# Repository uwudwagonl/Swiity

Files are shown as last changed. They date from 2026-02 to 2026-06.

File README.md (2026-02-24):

# Swiity – Vending Machine Project

**HTLVB 4AHWII Gruppe C**

A fully integrated vending machine project combining:

- **PLC / SPS control** – written in Structured Text (ST) with Automation Studio (B&R)
- **Arduino sensing** – sensor and actuator control via Arduino microcontrollers
- **Mechanical design** – CAD models, STL files, and 3D-printed parts
- **Electrical design** – wiring diagrams and schematics

---

## Repository Structure

```
Swiity/
├── AutomationStudio/          # PLC program (Structured Text, B&R Automation Studio)
│   └── VendingMachine/
│       ├── Main.st            # Main cyclic task
│       ├── StateMachine.st    # Vending state-machine logic
│       ├── Types.typ          # User-defined data types (UDTs)
│       └── Variables.var      # Global variable declarations
│
├── Arduino/                   # Arduino firmware for sensors & actuators
│   └── VendingMachine/
│       ├── VendingMachine.ino # Main Arduino sketch
│       ├── Sensors.h          # Sensor pin definitions and helper functions
│       └── Actuators.h        # Actuator pin definitions and helper functions
│
├── CAD/                       # Computer-aided design files
│   ├── Models/                # Native CAD source files (.step, .f3d, .sldprt, …)
│   └── Images/                # Rendered views and screenshots
│
├── 3DPrinting/                # 3D printing assets
│   ├── STL/                   # STL meshes ready for slicing
│   ├── GCode/                 # Sliced G-code files
│   └── PrintSettings/         # Slicer profiles / settings exports
│
├── Documentation/             # Project documentation
│   ├── Wiring/                # Wiring diagrams (PDF, PNG, Fritzing …)
│   ├── Schematics/            # Electrical schematics
│   └── BOM/                   # Bill of materials (BOM) spreadsheets
│
└── Images/                    # Project photos and renders
```

---

## Getting Started

### Automation Studio (PLC / SPS)

1. Open **B&R Automation Studio**.
2. Select *File → Open Project* and navigate to `AutomationStudio/VendingMachine/`.
3. Build the project (*Build → Build Solution*).
4. Transfer to the target controller via *Online → Transfer*.

### Arduino

1. Open `Arduino/VendingMachine/VendingMachine.ino` in the **Arduino IDE** (≥ 2.x).
2. Select the correct board and COM port.
3. Click *Upload*.

### 3D Printing

1. Find the desired part in `3DPrinting/STL/`.
2. Import the STL into your slicer (PrusaSlicer, Cura, …).
3. Load the matching profile from `3DPrinting/PrintSettings/` if available.
4. Slice, export G-code to `3DPrinting/GCode/`, and print.

---

## Requirements

| Component | Tool / Version |
|---|---|
| PLC code  | B&R Automation Studio 4.x, Structured Text (IEC 61131-3) |
| Arduino | Arduino IDE 2.x, Arduino Uno / Mega (or compatible) |
| CAD | Autodesk Fusion 360 / FreeCAD / SolidWorks |
| Slicing | PrusaSlicer / Cura |

---

## Contributing

1. Create a feature branch: `git checkout -b feature/<your-feature>`
2. Commit your changes with descriptive messages.
3. Open a Pull Request against `main`.

---

## License

See [LICENSE](LICENSE) for details.

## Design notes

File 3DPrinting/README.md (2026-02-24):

# 3DPrinting

3D printing assets for vending machine parts.

## Sub-folders

| Folder | Contents |
|---|---|
| `STL/` | Mesh files ready for slicing (exported from `CAD/Models/`) |
| `GCode/` | Sliced G-code ready to send to the printer |
| `PrintSettings/` | Slicer profiles / settings exports |

## Recommended Print Settings (starting point)

| Parameter | Value |
|---|---|
| Layer height | 0.2 mm |
| Infill | 20 % (structural parts: 40 %) |
| Perimeters | 3 |
| Supports | As needed |
| Material | PLA (enclosure) / PETG (load-bearing parts) |

## Naming Convention

STL files should mirror the CAD part number:

```
<PartNumber>_<Description>.stl
```

Example: `002_ProductSlotTray.stl`

## Workflow

1. Export `.stl` from the CAD model at the correct scale (mm, not inches).
2. Open in your slicer (PrusaSlicer / Cura).
3. Load the matching settings profile from `PrintSettings/`.
4. Slice and save the G-code to `GCode/` with the same part number prefix.
5. Transfer G-code to the printer (SD card / USB / OctoPrint).

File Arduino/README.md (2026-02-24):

# Arduino

Arduino firmware that handles **physical sensor reading** and **actuator driving**
for the vending machine, acting as the I/O front-end to the PLC.

## Files

| File | Purpose |
|---|---|
| `VendingMachine/VendingMachine.ino` | Main sketch – setup, loop, serial protocol |
| `VendingMachine/Sensors.h` | Sensor pin assignments and read helpers |
| `VendingMachine/Actuators.h` | Actuator pin assignments and control helpers |

## Wiring Summary

| Function | Arduino Pin | Notes |
|---|---|---|
| Coin sensor | D2 | Interrupt-capable |
| Product sensor | D3 | Interrupt-capable |
| Door sensor | D4 | Reed switch, INPUT_PULLUP |
| Temperature | A0 | NTC / DS18B20 |
| Stock sensors 0–7 | D5–D12 | IR reflection sensors |
| Motor enable | A1 | PWM output |
| Slot select bit 0 | A2 | 3-bit address LSB |
| Slot select bit 1 | A3 | 3-bit address |
| Slot select bit 2 | A4 | 3-bit address MSB |
| Change solenoid | A5 | Coin-return solenoid |
| Status LED | D13 | Built-in LED |
| Cooling fan | A6 | Relay output |

## Serial Protocol

Baud rate: **115 200**

### Arduino → PLC  (sensor report, sent every 100 ms)

```
S,<coin>,<product>,<door>,<temp>,<s0>,<s1>,<s2>,<s3>,<s4>,<s5>,<s6>,<s7>
```

- `coin`, `product`, `door`, `sN` – `0` or `1`
- `temp` – float (°C), one decimal place

Example: `S,0,0,0,6.4,1,1,1,0,1,1,1,1`

### PLC → Arduino  (actuator command)

```
A,<motorEn>,<slot>,<change>,<statusLED>,<fan>
```

- All fields – `0` or `1` (or slot index 0–7)

Example: `A,1,3,0,1,0`  → motor on, slot 3, change off, LED on, fan off

## How to Flash

1. Open `VendingMachine/VendingMachine.ino` in **Arduino IDE 2.x**.
2. Select the correct board (*Tools → Board*) and port (*Tools → Port*).
3. Click **Upload** (Ctrl + U).

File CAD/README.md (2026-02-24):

# CAD

Computer-Aided Design files for the vending machine enclosure and mechanical parts.

## Sub-folders

| Folder | Contents |
|---|---|
| `Models/` | Native CAD source files (`.f3d`, `.step`, `.iges`, `.sldprt`, …) |
| `Images/` | Rendered views, screenshots, and exploded diagrams |

## Recommended Naming Convention

```
<PartNumber>_<Description>_v<Version>.<ext>
```

Examples:
- `001_OuterEnclosure_v1.step`
- `002_ProductSlotTray_v2.f3d`
- `003_CoinChute_v1.step`

## Software

- **Autodesk Fusion 360** (`.f3d`) – preferred for collaborative editing
- **FreeCAD** (`.FCStd`) – open-source alternative
- **SolidWorks** (`.sldprt` / `.sldasm`) – if available at school

Always export a neutral `.step` file alongside the native format so any team
member can open the geometry regardless of which CAD tool they use.

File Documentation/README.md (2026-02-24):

# Documentation

Project documentation for the vending machine.

## Sub-folders

| Folder | Contents |
|---|---|
| `Wiring/` | Wiring diagrams (Fritzing `.fzz`, PDF exports, PNG images) |
| `Schematics/` | Electrical schematics (KiCad, Eagle, or PDF) |
| `BOM/` | Bill of Materials spreadsheets (`.csv` / `.xlsx`) |

## Document Naming Convention

```
<DocType>_<Description>_v<Version>.<ext>
```

Examples:
- `Wiring_ArduinoToSensors_v1.pdf`
- `Schematic_PowerSupply_v2.pdf`
- `BOM_ElectricalComponents_v1.csv`

## BOM Template

A BOM CSV should contain at minimum:

| Column | Description |
|---|---|
| `ItemNo` | Sequential item number |
| `Quantity` | Number of units required |
| `Description` | Human-readable description |
| `Manufacturer` | Manufacturer name |
| `PartNumber` | Manufacturer part number |
| `Supplier` | Where to order (e.g., DigiKey, Mouser, Conrad) |
| `SupplierPN` | Supplier part number |
| `UnitPrice` | Price per unit (€) |
| `Notes` | Any additional notes |

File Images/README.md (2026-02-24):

# Images

Project photos, renders, and progress pictures.

## What to add here

- Photos of the physical build at each stage
- Renders exported from `CAD/Images/`
- Screenshots of the Automation Studio HMI
- Any promotional or presentation images

## Naming Convention

```
<YYYY-MM-DD>_<Description>.<ext>
```

Examples:
- `2024-03-15_AssemblyFront.jpg`
- `2024-04-02_WiringComplete.jpg`
- `2024-05-10_FinalRender.png`

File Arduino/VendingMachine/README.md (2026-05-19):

# Snackomat ESP32-Firmware

Firmware für den Snackautomaten von Gruppe C (Swiity, Berufsschule).

## Hardware
- ESP32 DevKit (beliebige Variante mit ≥ 30 Pins)
- 4 × HC-SR04 Ultraschall-Sensor
- 4-Kanal Relais-Modul (active HIGH)
- 4 × DC-Getriebemotor 12 V
- PN532 NFC-Leser (I2C-Modus)
- 5 V Netzteil für ESP32, 12 V Netzteil für Motoren (getrennt!)

## Software-Setup

### 1. Arduino IDE konfigurieren
- Arduino IDE ≥ 2.0
- Board-Manager-URL ergänzen:
  `https://raw.githubusercontent.com/espressif/arduino-esp32/gh-pages/package_esp32_index.json`
- Board installieren: **esp32** von Espressif
- Board auswählen: *ESP32 Dev Module*

### 2. Libraries installieren (Library Manager)
- **Adafruit PN532** (aktuellste Version)
- **Adafruit BusIO** (wird automatisch mitgezogen)

`WiFi`, `Preferences`, `Wire` und `esp_task_wdt` sind im ESP32-Core enthalten.

### 3. Konfiguration anpassen
Öffne [config.h](snackomat/config.h) und passe an:
```cpp
#define WIFI_SSID      "Snackomat_WLAN"
#define WIFI_PASSWORD  "bitte-aendern"
#define PLC_IP         "192.168.2.20"      // Deine X20CP1382 IP
#define PLC_TCP_PORT   8000
```

NFC-Whitelist (Karten-UIDs) ebenfalls dort pflegen:
```cpp
static const char* NFC_WHITELIST[NFC_WHITELIST_MAX] = {
    "04A1B2C3D4",   // Schuelerkarte 1
    ...
};
```

### 4. Sketch öffnen und flashen
Öffne `snackomat/snackomat.ino` in der Arduino IDE. Klick auf **Upload**.

### 5. Serial-Monitor
Baudrate `115200`. Erwartete Ausgabe nach Boot:
```
================================================
  Snackomat ESP32-Firmware (Swiity Gruppe C)
================================================
[120ms] NVS geoeffnet (Namespace: snackomat)
[135ms] Sensor Fach 1 initialisiert (TRIG=26, ECHO=27)
...
[450ms] WLAN starte zu SSID 'Snackomat_WLAN' (non-blocking)
[5200ms] WLAN verbunden. IP: 192.168.2.99, RSSI: -63 dBm
[5400ms] TCP verbinde zu 192.168.2.20:8000 ...
[5500ms] TCP-Verbindung zur PLC steht
[5500ms] -> PLC: READY
```

## Dateiübersicht

| Datei | Zweck |
|---|---|
| [snackomat.ino](snackomat/snackomat.ino) | Hauptdatei, setup() + loop() |
| [config.h](snackomat/config.h) | Pins, Konstanten, WLAN, NFC-Whitelist |
| [hcsr04_sensor.h/.cpp](snackomat/hcsr04_sensor.cpp) | Ultraschall, Median aus 3 Messungen |
| [motor_control.h/.cpp](snackomat/motor_control.cpp) | DC-Motor via Relais, nicht-blockierend |
| [sps_communication.h/.cpp](snackomat/sps_communication.cpp) | TCP-Client zur PLC, Protokoll-Parser |
| [fach_manager.h/.cpp](snackomat/fach_manager.cpp) | Orchestriert Sensoren + Motoren (Round-Robin) |
| [preferences_manager.h/.cpp](snackomat/preferences_manager.cpp) | NVS: Kalibrierung, LEER/VOLL, Laufzeit |
| [nfc_reader.h/.cpp](snackomat/nfc_reader.cpp) | PN532 I2C, Whitelist-Prüfung |

## Protokoll (TCP/IP, ASCII, `\n`-getrennt)

### PLC → ESP32
| Befehl | Bedeutung |
|---|---|
| `M:1`  | Motor Fach 1 starten |
| `C:1`  | Fach 1 kalibrieren (Referenzwert speichern) |
| `S:1`  | Status Fach 1 anfordern |
| `A` | Status aller Fächer anfordern |
| `P:1,1.50` | Simulierte Zahlung 1,50 € Fach 1 → Motor starten |
| `PING` | Antwort: `PONG` |

### ESP32 → PLC
| Nachricht | Bedeutung |
|---|---|
| `READY` | System gebootet/verbunden |
| `OK:1` | Motor 1 gestartet |
| `DONE:1` | Motor 1 fertig (nach Laufzeit) |
| `LEER:1` / `VOLL:1` | Bestandsänderung Fach 1 |
| `DIST:1,23`  | Aktueller Abstand Fach 1 in cm |
| `STATUS:1,VOLL` | Antwort auf `S:1` |
| `NFC:04A1B2C3D4,OK` | Karte gescannt, in Whitelist |
| `NFC:04A1B2C3D4,UNBEKANNT` | Karte nicht in Whitelist |
| `PING` | Heartbeat alle 2 s |
| `ERR:WLAN,reconnect` | Fehlermeldung mit Quelle + Detail |

## Pin-Belegung (siehe auch Verkabelung.pdf)

| Komponente | ESP32 Pin |
|---|---|
| HC-SR04 Fach 1 | TRIG=26, ECHO=27 |
| HC-SR04 Fach 2 | TRIG=14, ECHO=12 |
| HC-SR04 Fach 3 | TRIG=33, ECHO=32 |
| HC-SR04 Fach 4 | TRIG=25, ECHO=35 |
| Relais Motor 1 | IN1=16 |
| Relais Motor 2 | IN2=17 |
| Relais Motor 3 | IN3=18 |
| Relais Motor 4 | IN4=19 |
| PN532 SDA | 21 |
| PN532 SCL | 22 |
| PN532 IRQ | 13 |
| PN532 RST | 15 |

## Troubleshooting

### ESP32 bootet in Endlosschleife
- Watchdog schlägt zu. Prüfe Serial-Output, Zeile vor Reset zeigt wo.
- Meist: fehlende Library oder falsche Pin-Nummer.

### Kein WLAN
- SSID/Passwort in config.h korrekt?
- X20CP1382 und ESP32 im gleichen Subnetz (Router-Subnet wie 192.168.2.x)?

### Keine TCP-Verbindung
- PLC-IP in config.h = tatsächliche IP der X20CP1382?
- PLC-Projekt auf X20CP1382 übertragen und läuft?
- Windows-Firewall blockiert Port 8000?

### HC-SR04 liest immer -1
- 5 V Versorgung am Sensor (nicht 3,3 V — HC-SR04 braucht 5 V)?
- TRIG/ECHO nicht verwechselt?

### PN532 nicht gefunden
- Modul im I2C-Modus konfiguriert (DIP-Schalter am Modul!)?
- SDA/SCL nicht verwechselt?
- 3,3 V an VCC (nicht 5 V)?

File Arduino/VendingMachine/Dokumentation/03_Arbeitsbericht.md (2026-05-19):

# Arbeitsbericht: HTLVB_Sweety_Basic → HTLVB_Sweety_new

Projekt Swiity Gruppe C (Berufsschule)
Erweiterung der Schul-Vorlage zum voll funktionsfähigen Snackautomaten
mit ESP32, NFC und TCP/IP-Kommunikation.

---

## 1. Gesamtziel

Die Basis-Vorlage `HTLVB_Sweety_Basic` bietet Grundgerüst für einen
Snackautomaten, steuert aber nur lokal über X20-I/O. Das neue Projekt
`HTLVB_Sweety_new` baut dieses Fundament um zu einem verteilten System
ESP32 ↔ PLC mit Karten-Zahlung und getrennter Hardware für die
Fach-Überwachung.

---

## 2. Hardware-Konfiguration (UNVERÄNDERT übernommen)

Nichts geändert:
- **CPU**: X20CP1382 (IP 192.168.2.20)
- **Panel**: 6PPT50.0502-10A
- **Digital-Input X1**: Münzeinwurf-Lichtschranke (DI01)
- **Digital-Output X3**: 4× Motor (DO01–DO04) + LED (DO05)
- **Analog-Output X20AO2622**: Motor-Geschwindigkeit
- **Automation Runtime**: G4.83

---

## 3. Task-Struktur: ST → ANSI C++ ersetzt

### Entfernt
| Task (Vorlage) | Sprache | Zweck | Ersetzt durch |
|---|---|---|---|
| `visumanager` | Structured Text | Seiten-Navigation, Sprachumschaltung | Program (ANSI C++) |
| `produktausgabe` | Structured Text | Zahlungs-Statemachine, Motorausgabe | Program (ANSI C++) |
| `motorman` | Structured Text | Motor-Tippbetrieb, Settings | Program (ANSI C++) |

### Neu
| Task | Sprache | Zweck |
|---|---|---|
| `Program` | ANSI C++ | Gesamte Geschäftslogik + TCP-Server |
| `Program1` | ANSI C++ | Münz-Zählung mit Entprellung |

**Warum**: Vorgabe des Users — komplette Umstellung auf C++.

---

## 4. Globale Typen (Global.typ) — ERWEITERT

Aus Vorlage beibehalten:
- `eVisuPages` (Seiten-Enum)
- `tVisu_page`, `tVisu_buttons`, `tVisu_settings`, `tVisu`

Neu hinzugefügt (für Snackomat):
- `tFach` – Fach-Info (Abstand, istLeer, Referenz, Preis, Name)
- `tAuswahl` – aktuelle Kundenauswahl
- `tZahlung` – Zahlungsmodus (0=idle, 1=Bar, 2=Karte), Status, Startzeit
- `tNfcInfo` – UID, Whitelist-Status, Zeitstempel
- `tMuenze` – Impulse, Summe, Wert pro Impuls
- `tEspStatus` – ESP32-Verbindung, letzter Ping, Fehlerzähler

Seiten-Enum erweitert:
- Neu: `_20_BarBezahlen`, `_30_KarteBezahlen`, `_40_Ausgabe`, `_50_Danke`, `_90_Fehler`

Button-Struct erweitert:
- Neu: `P10_WaehleBar`, `P10_WaehleKarte`
- Neu: `P20_BestaetigeBar`, `P30_BestaetigeKarte`
- Neu: `PXX_Abbrechen`
- Neu: `P910_Kalibriere1..4`

Settings-Struct erweitert:
- Neu: `muenzwertCent`, `preisCent[0..3]`

---

## 5. Globale Variablen (Global.var) — ERWEITERT

Aus Vorlage beibehalten:
- `Visu`, `aoMotorspeed`, `psMotorspeed`, `diMuenzeinwurf`
- `doMotor[0..3]`, `doLedEin`
- `Perm_ptMotorX[0..3]` (RETAIN)

Neu hinzugefügt:
- `gFach[0..3]` – Fach-Bestandsdaten
- `gSel` – aktuelle Auswahl
- `gPay` – Zahlungsvorgang
- `gNfc` – NFC-Info (kommt vom ESP32)
- `gCoin` – Münzzähler
- `gEsp` – ESP32-Verbindungsstatus
- `do_Relais` – zusätzliches Freigaberelais
- `Perm_preisCent[0..3]`, `Perm_motorLaufzeit[0..3]`, `Perm_muenzwert` (RETAIN)

---

## 6. Visualisierung (Logical/Visu)

### Aus Vorlage beibehalten
- Layout-Basis 800×480 WVGA
- Seiten `_00_Init`, `_10_Main`, `_900_Settings`, `_910_Settings1`
- VCShared, Fonts, Bitmaps, Layers, Styles komplett unverändert
- HotSpots in den 4 Ecken von `_10_Main` (technisch noch da, ohne Funktion)

### Neu
- **5 neue Seiten** als XML-Skelette (Widgets manuell in AS hinzuzufügen):
  - `_20_BarBezahlen.page` (Münzzähler + Bestätigen)
  - `_30_KarteBezahlen.page` (Karte auflegen + NFC-Status)
  - `_40_Ausgabe.page` (Motor-Fortschritt)
  - `_50_Danke.page` (Dankeschön nach Ausgabe)
  - `_90_Fehler.page` (Fehlermeldung)
- Registrierung aller 9 Seiten in `Visu/Package.vcp`
- `DefaultPage` auf `_00_Init` (unverändert)
- `PageChangeDatapoint` auf `Visu.page.setpage` (aus Vorlage)

---

## 7. Hardware-Schnittstelle (IoMap.iom) — UNVERÄNDERT

```
::aoMotorspeed AT %QW."X20AO2622".AnalogOutput01;
::diMuenzeinwurf AT %IX."X1".DigitalInput01;
::doMotor[0..3] AT %QX."X3".DigitalOutput01..04;
doLedEin AT %QX."X3".DigitalOutput05;
```

1:1 aus Vorlage übernommen.

---

## 8. Logik-Funktionalität

### Aus Vorlage beibehalten (neu in C++ geschrieben)

| Funktion | Vorlage (ST) | Neu (ANSI C++) |
|---|---|---|
| Startscreen mit Timer | `visumanager: tStartScreen 5s` | `Cyclic.cpp: jetztMs >= 3000` |
| Seitenwechsel Settings ↔ Main | `tOpenSettings TON` | Lang-Druck 2s auf `PXX_GotoSettings` |
| Settings-Unterseiten durchblättern | `PXX_SettingsNextPage/Prev` | gleich, via `Cyclic.cpp` |
| Motor-Tippbetrieb in Settings | `motorman: P910_MoveMotor` | `Cyclic.cpp` Settings-Sektion |
| Motor-Laufzeit pro Fach speichern | `Perm_ptMotorX[]` | `Perm_ptMotorX[]` + `Perm_motorLaufzeit[]` |
| Sprachumschaltung de/en | `visumanager` Text-Swap | `Cyclic.cpp` Sprachblock |
| Produkt-Texteingabe | `Text_Selection_Visu[]` | gleich + schreibt zusätzlich `gFach[i].name` |
| Münz-Zählung mit Entprellung | `produktausgabe: tVzgMuenzeinwurf` | `Program1/Cyclic.cpp` mit 20 ms Entprellung |
| Direkte Motor-Ausgabe | `produktausgabe: doMotor[i]` | `Cyclic.cpp` Fallback wenn ESP32 offline |
| Zustandsautomat Zahlung | `sStepAusgabe CASE` | `stateZahlung switch-case` |

### Komplett NEU (nicht in Vorlage vorhanden)

| Feature | Code-Stelle |
|---|---|
| **TCP-Server auf Port 8000** | `Cyclic.cpp: stateTcp` + AsTCP-Library |
| **ASCII-Protokoll Parser** (READY, OK:n, DONE:n, LEER:n, VOLL:n, DIST:n, STATUS:n, NFC:UID, PING, ERR:…) | `verarbeiteZeile()` |
| **Bar/Karte-Auswahl** | `stateZahlung 1 → 2 (Bar) oder 3 (Karte)` |
| **NFC-Karten-Flow** | `stateZahlung 3`: wartet auf `gNfc.inWhitelist` |
| **Motor-Trigger via TCP** | `stateZahlung 6`: sendet `M:n` an ESP32 |
| **Fallback direkt doMotor** | falls `gEsp.verbunden == 0` |
| **Watchdog-Timeout für Motor** | 8 s hartes Safety-Timeout |
| **ESP32-Heartbeat-Monitoring** | `gEsp.letzterPingMs + TIMEOUT_ESP_HEARTBEAT_MS` |
| **Kalibrier-Command an ESP32** | Buttons `P910_Kalibriere1..4` senden `C:n` |
| **Abbrechen-Button global** | `PXX_Abbrechen` setzt Statemaschine zurück |

---

## 9. Neue Libraries

| Library | Zweck | Herkunft |
|---|---|---|
| **AsTCP** | TCP/IP Socket-Funktionen | aus AS-Installation kopiert |

Ergänzt in `Logical/Libraries/Package.pkg` und `Cpu.sw`.

---

## 10. Konnektivität & OPC-UA

Neu:
- `Physical/Config1/X20CP1382/Connectivity/OpcUA/OpcUaMap.uad` — exponiert alle
  Snackomat-Variablen für Claude-MCP-Tests
- `AccessAndSecurity/UserRoleSystem/User.user` — Admin/password User hinzugefügt
  (für OPC-UA-Auth)

---

## 11. ESP32-Firmware (komplett neu – nicht in Vorlage)

Ordner: `ESP32_Firmware/snackomat/`

| Datei | Inhalt |
|---|---|
| `snackomat.ino` | Hauptdatei, setup/loop, Watchdog |
| `config.h` | Pins, WLAN, TCP, Whitelist |
| `hcsr04_sensor.h/.cpp` | Ultraschall-Messung, Median aus 3, Round-Robin |
| `motor_control.h/.cpp` | DC-Motor via Relais, nicht-blockierend, per-Fach-Laufzeit |
| `sps_communication.h/.cpp` | TCP-Client, Reconnect, PING/PONG, Fehler-Codes |
| `fach_manager.h/.cpp` | Orchestriert 4 Fächer, LEER/VOLL-Detection |
| `preferences_manager.h/.cpp` | NVS-Speicher für Kalibrierung + Motorlaufzeit |
| `nfc_reader.h/.cpp` | PN532 I2C, Whitelist-Prüfung |

---

## 12. Dokumentation

Neu:
- `01_Verkabelung.pdf` – Stückliste, Pin-Tabellen, Inbetriebnahme
- `02_Visu_Anleitung.pdf` – Schritt-für-Schritt Widget-Anleitung für AS
- `03_Arbeitsbericht.md` – dieses Dokument
- `README.md` im ESP32_Firmware-Ordner

---

## 13. Zusammenfassung: Was ist wirklich neu?

**Aus Vorlage komplett übernommen**: Hardware-Konfig, VC4-Design-System
(Bitmaps, Fonts, Styles, Layer), Produktfach-Grundidee,
Münzzähler-Prinzip, Sprach-Umschaltung, Settings-Architektur.

**In andere Sprache portiert**: alle 3 ST-Tasks → ANSI C++.

**Hinzugefügt**:
1. Distribuierte Architektur mit ESP32 über TCP/IP
2. Kartenzahlung via PN532 NFC + Whitelist
3. Zwei-Wege-Zahlung (Bar oder Karte) mit eigenen Visu-Seiten
4. Bestandsüberwachung pro Fach (HC-SR04 LEER/VOLL)
5. OPC-UA-Freigabe für MCP-basierte Tests
6. Robustheit: Heartbeat, Watchdog, Safety-Timeouts, Fallback-Modus

**Unverändert**: Alles was die Schule physisch vorgegeben hat
(CPU-Typ, I/O-Module, Panel, Ethernet-IP).

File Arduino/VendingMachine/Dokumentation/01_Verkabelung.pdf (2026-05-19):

# Snackomat - Verkabelung & Inbetriebnahme

Berufsschulprojekt Gruppe C (Swiity). Diese Anleitung fuehrt Schritt fuer Schritt durch den Aufbau.

## 1. Uebersicht

Der Automat besteht aus zwei intelligenten Einheiten:
- B&R X20CP1382 + 6PPT50 Panel (Touchscreen + SPS) - bedient die Visualisierung, zaehlt Muenzen und schaltet das Freigaberelais.
- ESP32 - liest die 4 HC-SR04 Fuellstandssensoren, den PN532 NFC-Leser und steuert die 4 DC-Motoren ueber Relais.
Die beiden Einheiten kommunizieren ueber LAN (TCP/IP, Port 8000). Der ESP32 verbindet sich als Client zur PLC-IP 192.168.2.20.

## 2. Benoetigte Teile (Stueckliste)

Pos | Bauteil | Menge | Anmerkung
1 | ESP32 DevKit (30 Pin) | 1 | mit USB-C oder Micro-USB
2 | HC-SR04 Ultraschall-Sensor | 4 | 5V Versorgung!
3 | Relais-Modul 4-Kanal 5V | 1 | active HIGH
4 | DC-Getriebemotor 12V | 4 | je Fach einer
5 | PN532 NFC-Modul | 1 | im I2C-Modus
6 | X20CP1382 CPU | 1 | bereits vorhanden
7 | 6PPT50.0502-10A Panel | 1 | Touchscreen, VNC auf 5900
8 | X20DI (X1) - Muenzeinwurf | 1 | Lichtschranke DI01
9 | X20DO (X3) - 4x Motor + LED | 1 | DO01-DO04 Motoren, DO05 LED
10 | X20AO2622 Motor-Speed (Analog) | 1 | Geschwindigkeit 0-10V
11 | Lichtschranke (1-Kanal) | 1 | Muenzkanal
12 | Netzteil 5V 3A | 1 | fuer ESP32+Relais+HC-SR04
13 | Netzteil 12V 5A | 1 | fuer DC-Motoren
14 | Reihenklemmen Weidmueller ZDK 2,5 | ca. 30
15 | LAN-Kabel (Cat5 oder besser) | 2 | 1x X20CP1382, 1x ESP32 (via Router)
16 | Ethernet-Router/Switch | 1 | WLAN + LAN gemeinsam
17 | Jumperkabel/Lappkabel div. | -

## 3. Pin-Belegung ESP32

### 3.1 HC-SR04 Ultraschallsensoren

Fach | TRIG (GPIO) | ECHO (GPIO) | VCC | GND
1 | 26 | 27 | 5V | GND
2 | 14 | 12 | 5V | GND
3 | 33 | 32 | 5V | GND
4 | 25 | 35 | 5V | GND

Achtung: HC-SR04 braucht 5V - an 3,3V antwortet er nicht oder falsch. ECHO liefert zwar 5V-Pegel, der ESP32 vertraegt das an den gewaehlten Input-Pins, aber sicherheitshalber einen 1k/2k Spannungsteiler einbauen, wenn du auf Nummer sicher gehen willst.

### 3.2 Relais-Modul (Motorsteuerung)

Relais | Steuer-Pin (GPIO) | Last (Motor an NO/COM)
IN1 - Motor Fach 1 | 16 | 12V + Motor 1
IN2 - Motor Fach 2 | 17 | 12V + Motor 2
IN3 - Motor Fach 3 | 18 | 12V + Motor 3
IN4 - Motor Fach 4 | 19 | 12V + Motor 4

Versorgung Relais-Modul: VCC = 5V (ESP32-Netzteil), GND = GND. Zusaetzlich Jumper JD-VCC oeffnen und auf 12V des Motor-Netzteils legen (Optokoppler-Trennung).
Achtung: 5V und 12V GND muessen verbunden sein (gemeinsame Masse), sonst schaltet das Relais nicht. Aber: niemals 5V+ und 12V+ verbinden!

### 3.3 PN532 NFC-Modul (I2C)

PN532 Pin | ESP32 Pin | Anmerkung
VCC | 3V3 | NICHT 5V!
GND | GND
SDA | GPIO 21 | I2C Daten
SCL | GPIO 22 | I2C Takt
IRQ | GPIO 13 | Interrupt
RST | GPIO 15 | Reset

Achtung: Am PN532-Modul gibt es DIP-Schalter fuer den Modus. Fuer unser Setup muss I2C aktiv sein: SEL0 = AUS (OFF), SEL1 = EIN (ON).

## 4. Verdrahtung X20CP1382 & X20-Module

Hinweis: Die Hardware-Konfiguration kommt aus dem Schul-Basisprojekt und ist bereits im AS-Projekt angelegt (IoMap.iom). Die Klemmen-Bezeichnungen hier entsprechen dem AS-Projekt.

### 4.1 Lichtschranke am Muenzkanal (Modul X1)

Signal | X1 Klemme | AS-Variable
+24V (Versorgung Lichtschranke) | 24V+ | -
Ausgang Lichtschranke (Signal) | DI 01 | diMuenzeinwurf
GND | GND | -
Hinweis: Die Muenz-Zaehlung erfolgt im Task Program1 in Logical/Program1/Cyclic.cpp. Zaehler: gCoin.summeCent (jeder Impuls = gCoin.wertProImpulsCent, Default 10 Cent).

### 4.2 Motoren + LED am Digital-Output (Modul X3)

Signal | X3 Klemme | AS-Variable
Motor Fach 1 | DO 01 | doMotor[0]
Motor Fach 2 | DO 02 | doMotor[1]
Motor Fach 3 | DO 03 | doMotor[2]
Motor Fach 4 | DO 04 | doMotor[3]
LED-Beleuchtung | DO 05 | doLedEin

Hinweis: doMotor[] wird von der PLC als Fallback genutzt, falls ESP32 nicht verbunden ist. Im Normalbetrieb steuert der ESP32 die Motoren ueber seine eigenen Relais (siehe Abschnitt 3.2).

### 4.3 Motor-Speed Analog (Modul X20AO2622)

Optional: Analog-Output fuer variable Motor-Geschwindigkeit. Variable aoMotorspeed (0-32767 = 0-10V).

### 4.4 Ethernet / Netzwerk

Die X20CP1382 hat IP 192.168.2.20 (siehe Cpu.pkg). ESP32 muss im gleichen Subnetz sein. Empfehlung: Router mit DHCP auf 192.168.2.x konfigurieren, ESP32 bekommt dann automatisch eine IP.

Geraet | Anschluss | Ziel
X20CP1382 CPU | ETH1 | Switch/Router
6PPT50 Panel | ETH | gleicher Switch (VNC ueber Panel)
ESP32 | WLAN | gleicher Router
Laptop (Entwicklung) | LAN/WLAN | gleicher Router (fuer AS + ESP32-Upload)

## 5. Stromversorgung

Verbraucher | Spannung | Max. Strom | Quelle
ESP32 + HC-SR04 + Relais-Spulen | 5V | ~1,5 A | Netzteil 1 (5V 3A)
PN532 NFC-Modul | 3,3V | ~0,1 A | ESP32 3V3 Pin
DC-Motoren (ueber Relais) | 12V | je ~1 A | Netzteil 2 (12V 5A)
Lichtschranke | 24V | 0,05 A | X20 Powersupply oder 24V NT
X20CP1382 + 6PPT50 Panel | 24V | ~1,5 A | Panel-Netzteil
Achtung: Alle Massen (GND) miteinander verbinden - sonst gibt es unvorhersagbares Verhalten. Ausnahme: 24V-Bereich der PLC darf galvanisch getrennt bleiben, muss dann aber ueber Relais/Koppler laufen.

## 6. Aufbau Schritt fuer Schritt

1 Alle Netzteile ausschalten.
2 Reihenklemmen-Leiste montieren (Weidmueller ZDK 2,5).
3 5V-Netzteil an ESP32 (Vin oder 5V Pin) anschliessen. GND nicht vergessen.
4 HC-SR04-Sensoren 1-4 an die jeweiligen GPIO-Pins (siehe Tabelle 3.1) klemmen.
5 Relais-Modul an 5V/GND + IN1-IN4. JD-VCC-Jumper abziehen, JD-VCC an 12V-Netzteil+. 6 DC-Motoren an NO+COM der Relais-Kontakte. 12V+ an COM, Motor zwischen NO und 12V-.
7 PN532 an 3V3/GND, SDA=21, SCL=22, IRQ=13, RST=15. DIP-Schalter I2C.
8 Lichtschranke an X20 Modul X1 DI01 + 24V Versorgung.
9 X20CP1382 + 6PPT50 Panel ueber Ethernet an Switch/Router. 24V-Netzteil an die oberen Klemmen (24V/GND).
10 Netzteile nacheinander einschalten: zuerst 24V (PLC), dann 5V (ESP32), zuletzt 12V (Motoren).
11 Panel bootet (AR G4.83). ESP32 bootet via USB-Power, wenn angesteckt. Im normalen Betrieb laeuft ESP32 ueber 5V-Netzteil.

## 7. Erstes Hochfahren - Checkliste

Nr | Schritt | Erwartung
1 | ESP32 an Arduino IDE, Serial Monitor 115200 | Boot-Meldung 'Snackomat ESP32-Firmware'
2 | config.h: WIFI_SSID und WIFI_PASSWORD anpassen | Upload erfolgreich
3 | Serial: WLAN verbinde... -> verbunden. IP: ... | innerhalb 20 s
4 | Serial: TCP verbinde zu 192.168.2.20:8000 | 'TCP-Verbindung zur PLC steht'
5 | PLC: Variable <b>gEsp.verbunden</b> via OPC-UA | TRUE
6 | Variable <b>Visu.page.actpage</b> | 0 (Init) oder 10 (Main)
7 | Muenze einwerfen - <b>gCoin.summeCent</b> | erhoeht sich um Wert pro Impuls (Default 10)
8 | Karte an PN532 halten - <b>gNfc.uidHex</b> | HEX-UID erscheint, gNfc.inWhitelist pruefen
Hinweis: Zum Live-Testen per Claude MCP: sag einfach 'Lies die Variable Visu.page.actpage aus der PLC', dann wird per OPC-UA abgefragt.

## 8. Troubleshooting

Problem | Ursache | Fix
ESP32 rebootet endlos | Watchdog oder fehlende Lib | Serial-Log pruefen
HC-SR04 misst -1 | falsche Spannung (3,3V statt 5V) | auf 5V umklemmen
Relais klickt nicht | GND nicht verbunden | 5V-GND und 12V-GND bruecken
TCP verbindet nicht | falsche IP oder PLC nicht aktiv | in config.h PLC_IP pruefen, 'ping 192.168.2.20'
PN532 nicht erkannt | I2C DIP-Schalter falsch | SEL0 OFF, SEL1 ON setzen
Muenze zaehlt nicht | Lichtschranke prellt | Entprellzeit in Program1 Variables.var (entprellungMs) erhoehen
Motor laeuft zu kurz/lang | MOTOR_LAUFZEIT_DEFAULT_MS | in config.h anpassen oder per OPC-UA Perm_motorLaufzeit[n] setzen

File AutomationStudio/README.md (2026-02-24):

# AutomationStudio

Structured Text (ST) source code for the vending machine PLC / SPS controller,
developed with **B&R Automation Studio** (IEC 61131-3).

## Files

| File | Purpose |
|---|---|
| `Main.st` | Main cyclic program – entry point called every PLC scan |
| `StateMachine.st` | Vending state-machine function block (idle → coin → select → dispense → collect → change) |
| `Types.typ` | User-defined data types (enums, structs) |
| `Variables.var` | Global variable and constant declarations |

## State Machine Overview

```
IDLE ──► COIN_CHECK ──► SELECT ──► DISPENSE ──► COLLECT ──► CHANGE ──► IDLE
  ▲                                                                       │
  └────────────────────────────── (no change due) ───────────────────────┘

Any state ──► MAINTENANCE  (when service door opens)
Any state ──► ERROR        (on fault condition)
ERROR     ──► IDLE         (after 5 s auto-reset)
```

## How to Open in Automation Studio

1. Launch **B&R Automation Studio 4.x**.
2. *File → Open Project* → select this folder.
3. Assign the correct hardware configuration for your PLC target.
4. *Build → Build Solution* to compile.
5. *Online → Transfer* to deploy to the controller.

## I/O Mapping

Sensors and actuators are exchanged with the Arduino layer via digital/analog
I/O or a serial interface. Map the `gSensors` and `gActuators` global variables
to the corresponding hardware channels in the Automation Studio I/O mapping editor.

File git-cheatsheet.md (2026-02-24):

# Git Anleitung

## Repository klonen

### Mit SSH
- git clone git@github.com:uwudwagonl/Swiity.git

### Mit HTTPS
- git clone https://github.com/uwudwagonl/Swiity.git

## Remote Repository aktualisieren

- git pull origin main

### Bei Problemen
- git stash
- git clean -fd
- git pull origin main

Wichtig:
- git clean -fd löscht nur ungetrackte Dateien.
- Der Stash wird nicht automatisch gelöscht.
- Mit git stash list kannst du prüfen, ob dein Stash noch existiert.
- Mit git stash pop kannst du ihn wiederherstellen.

## Änderungen hochladen

- git add .
- git commit -m "Nachricht"
- git push origin main

### Bei Problemen
- git pull origin main
- git push origin main

Falls Merge-Konflikte auftreten, müssen diese zuerst manuell gelöst werden.

Tipp:
Vor jedem git push am besten einmal git pull origin main ausführen, um Konflikte zu vermeiden.

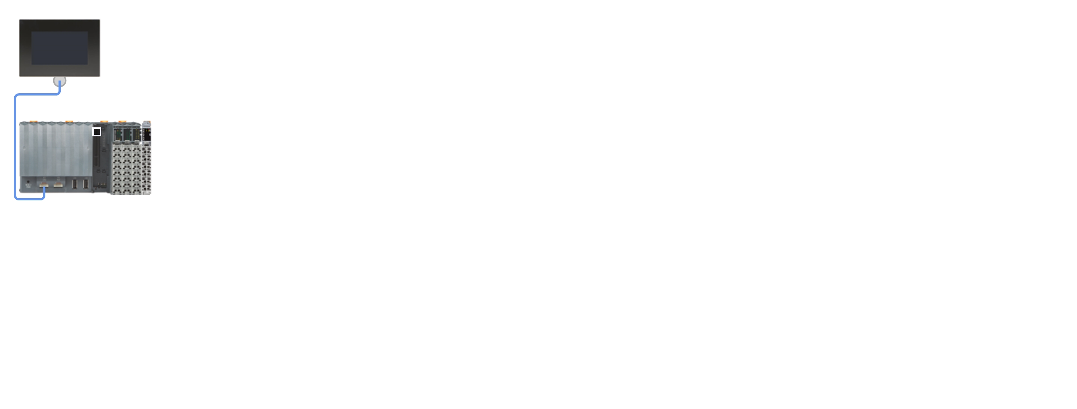
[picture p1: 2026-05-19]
AutomationStudio/VendingMachine/Physical/Swiity_Automat/Hardware.jpg

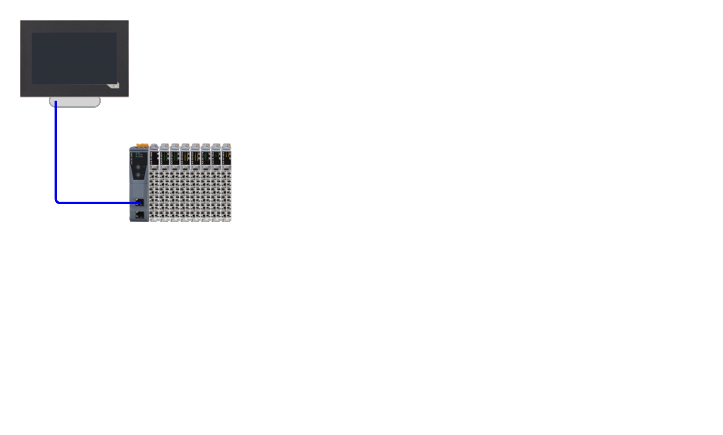
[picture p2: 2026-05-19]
AutomationStudio/VendingMachine/Physical/ALAB_PPC70/Hardware.jpg

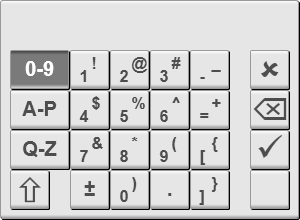
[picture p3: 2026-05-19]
AutomationStudio/VendingMachine/Logical/Visu/Bitmaps/Key_AlphaPadQVGA_Layer1.png

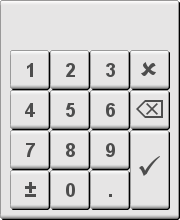
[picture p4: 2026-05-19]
AutomationStudio/VendingMachine/Logical/Visu/Bitmaps/Key_NumPad.png

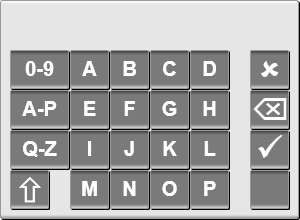
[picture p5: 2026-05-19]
AutomationStudio/VendingMachine/Logical/Visu/Bitmaps/Key_AlphaPadQVGA_Layer2_pressed.png

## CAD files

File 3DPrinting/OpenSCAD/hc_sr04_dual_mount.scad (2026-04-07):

// HC-SR04 Dual Sensor Mount (vertical) for Swiity Vending Machine
// 2 sensors stacked vertically, 65mm apart (center-to-center)
// Print this twice for all 4 slots
//
// HC-SR04 dimensions:
//   PCB: 45.0 x 20.0 x 15.0 mm
//   Transducer diameter: 16.0 mm
//   Transducer center-to-center: 26.0 mm

// --- Parameters ---

// Sensor dimensions
sensor_w      = 45.0;
sensor_d      = 20.0;
trans_dia     = 16.0;
trans_spacing = 26.0;

// Mount config
sensor_gap    = 65.0;   // vertical center-to-center between the two sensors
wall          = 2.0;
tolerance     = 0.4;
base_thick    = 3.0;
lip_height    = 5.0;
mount_hole_d  = 4.0;    // M3 clearance
mount_hole_inset = 5.0;

// Derived
slot_w = sensor_w + tolerance * 2;
slot_d = sensor_d + tolerance * 2;
trans_hole_d = trans_dia + tolerance * 2;

// The two sensor slots are centered vertically with sensor_gap between them
// Total height of the bracket
slot_center_1 = wall + slot_d / 2;
slot_center_2 = slot_center_1 + sensor_gap;

total_w = slot_w + wall * 2;
total_h = slot_center_2 + slot_d / 2 + wall;
total_depth = base_thick + lip_height;

module sensor_slot(y_offset) {
    // PCB pocket
    translate([wall, y_offset, base_thick])
        cube([slot_w, slot_d, lip_height + 1]);

    // Transducer holes through the base plate
    for (dx = [-trans_spacing/2, trans_spacing/2]) {
        translate([wall + slot_w/2 + dx, y_offset + slot_d/2, -0.1])
            cylinder(h = base_thick + 0.2, d = trans_hole_d, $fn = 48);
    }

    // Wire cutout at the top of each slot for the pin header
    translate([wall + slot_w/2 - 8, y_offset + slot_d - 1, base_thick])
        cube([16, wall + 2, lip_height + 1]);
}

module mount_holes() {
    positions = [
        [mount_hole_inset, mount_hole_inset],
        [total_w - mount_hole_inset, mount_hole_inset],
        [mount_hole_inset, total_h - mount_hole_inset],
        [total_w - mount_hole_inset, total_h - mount_hole_inset],
        // Extra pair between the two sensors for rigidity
        [mount_hole_inset, (slot_center_1 + slot_center_2) / 2],
        [total_w - mount_hole_inset, (slot_center_1 + slot_center_2) / 2],
    ];
    for (p = positions) {
        translate([p[0], p[1], -0.1])
            cylinder(h = base_thick + 0.2, d = mount_hole_d, $fn = 32);
    }
}

// --- Main body ---
difference() {
    cube([total_w, total_h, total_depth]);

    // Sensor slot 1 (bottom)
    sensor_slot(slot_center_1 - slot_d / 2);

    // Sensor slot 2 (top, 65mm above)
    sensor_slot(slot_center_2 - slot_d / 2);

    // Mounting holes
    mount_holes();
}

// --- Reinforcement rib between the two slots ---
rib_y1 = slot_center_1 + slot_d / 2 + wall;
rib_y2 = slot_center_2 - slot_d / 2 - wall;
rib_height = rib_y2 - rib_y1;
if (rib_height > 2) {
    // Center rib
    translate([total_w / 2 - 1.5, rib_y1, 0])
        cube([3, rib_height, total_depth]);
}

// --- Label ---
translate([total_w / 2, wall / 2, total_depth - 0.5])
    rotate([90, 0, 0])
        linear_extrude(0.6)
            text("SWIITY", size = 4, halign = "center", font = "Liberation Sans:style=Bold");

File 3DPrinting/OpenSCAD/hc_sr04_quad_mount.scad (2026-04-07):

// HC-SR04 Quad Sensor Mount for Swiity Vending Machine
// Holds 4 HC-SR04 ultrasonic sensors side by side
//
// HC-SR04 dimensions (from datasheet):
//   PCB: 45.0 x 20.0 x 15.0 mm
//   Transducer diameter: 16.0 mm
//   Transducer center-to-center: 26.0 mm
//   4-pin header pitch: 2.54 mm
//   Mounting holes: ~1.0 mm diameter at corners

// --- Parameters (tweak to fit your print / layout) ---

// Sensor dimensions
sensor_w     = 45.0;   // PCB width
sensor_h     = 20.0;   // PCB height (depth into mount)
sensor_thick = 1.6;    // PCB thickness
trans_dia    = 16.0;   // transducer cylinder diameter
trans_height = 12.0;   // transducer cylinder protrusion
trans_spacing = 26.0;  // center-to-center of the two transducers

// Mount config
num_sensors  = 4;
slot_gap     = 4.0;    // gap between sensor slots
wall         = 2.0;    // wall thickness around each slot
tolerance    = 0.4;    // print tolerance per side
base_thick   = 3.0;    // bottom plate thickness
lip_height   = 5.0;    // how far the side walls come up to hold the PCB
mount_hole_d = 4.0;    // M3 screw + clearance for mounting the bracket itself
mount_hole_inset = 5.0;

// Derived
slot_w = sensor_w + tolerance * 2;
slot_d = sensor_h + tolerance * 2;
total_w = num_sensors * (slot_w + wall) + wall + (num_sensors - 1) * slot_gap;
total_d = slot_d + wall * 2;
trans_hole_d = trans_dia + tolerance * 2;

module sensor_slot(x_offset) {
    translate([x_offset, wall, base_thick]) {
        // PCB slot (cut through the lip walls)
        cube([slot_w, slot_d, lip_height + 1]);
    }
    // Transducer holes through the base
    for (dx = [-trans_spacing/2, trans_spacing/2]) {
        translate([x_offset + slot_w/2 + dx, wall + slot_d/2, -0.1])
            cylinder(h = base_thick + 0.2, d = trans_hole_d, $fn = 48);
    }
    // Wire slot at the back for the pin header
    translate([x_offset + slot_w/2 - 8, wall + slot_d - 1, base_thick])
        cube([16, wall + 2, lip_height + 1]);
}

module mount_holes() {
    // Four corner mounting holes
    positions = [
        [mount_hole_inset, mount_hole_inset, -0.1],
        [total_w - mount_hole_inset, mount_hole_inset, -0.1],
        [mount_hole_inset, total_d - mount_hole_inset, -0.1],
        [total_w - mount_hole_inset, total_d - mount_hole_inset, -0.1],
    ];
    for (p = positions) {
        translate(p)
            cylinder(h = base_thick + 0.2, d = mount_hole_d, $fn = 32);
    }
}

// --- Main body ---
difference() {
    // Outer shell: base plate + lip walls
    cube([total_w, total_d, base_thick + lip_height]);

    // Cut the sensor slots
    for (i = [0 : num_sensors - 1]) {
        x = wall + i * (slot_w + wall + slot_gap);
        sensor_slot(x);
    }

    // Mounting holes
    mount_holes();
}

// --- Label ---
// Small embossed text on the front
translate([total_w / 2, 0.5, base_thick + lip_height - 0.5])
    rotate([90, 0, 0])
        linear_extrude(0.6)
            text("SWIITY", size = 5, halign = "center", font = "Liberation Sans:style=Bold");

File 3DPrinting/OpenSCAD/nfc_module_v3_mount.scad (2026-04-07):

// Elechouse NFC Module V3 (PN532) Mount for Swiity Vending Machine
// Snap-fit / screw-mount case for the PN532 NFC reader
//
// PN532 V3 dimensions (from elechouse.com):
//   PCB: 42.7 x 40.4 x 4.0 mm (including components)
//   Mounting holes: 4x at corners, ~2.0 mm diameter
//   Mounting hole inset: ~2.5 mm from edges
//   Pin header: 8-pin, 2.54 mm pitch, along one short edge
//   Antenna: integrated, on the front face of the PCB

// --- Parameters ---

// PCB dimensions
pcb_w      = 42.7;   // width
pcb_d      = 40.4;   // depth
pcb_thick  = 4.0;    // component height (top side)
pcb_bot    = 1.2;    // component height (bottom side / solder joints)

// Mounting holes on the PCB
pcb_hole_d     = 2.0;
pcb_hole_inset = 2.5;  // from PCB edges to hole center

// Mount config
wall        = 2.0;
tolerance   = 0.3;
base_thick  = 2.0;
lip_height  = 2.5;   // lip to hold the PCB from the sides
post_h      = pcb_bot + 0.5; // standoff height to lift PCB off base
screw_d     = 2.2;   // M2 screw hole in standoffs
screw_head  = 4.0;   // M2 screw head clearance

// Faceplate window: the NFC antenna area should be unobstructed
// The antenna occupies roughly the center of the PCB
antenna_w   = 34.0;
antenna_d   = 32.0;

// Bracket mounting holes (to mount the whole thing to the vending machine)
bracket_hole_d = 4.0;  // M3 clearance
bracket_ear_w  = 10.0;
bracket_ear_h  = base_thick;

// Derived
inner_w = pcb_w + tolerance * 2;
inner_d = pcb_d + tolerance * 2;
outer_w = inner_w + wall * 2;
outer_d = inner_d + wall * 2;
total_h = base_thick + post_h + pcb_thick + lip_height;

// --- Modules ---

module standoff(x, y) {
    translate([wall + tolerance + x, wall + tolerance + y, base_thick]) {
        difference() {
            cylinder(h = post_h, d = 5.0, $fn = 24);
            translate([0, 0, -0.1])
                cylinder(h = post_h + 0.2, d = screw_d, $fn = 20);
        }
    }
}

module pcb_screw_positions() {
    // 4 corners of the PCB
    offsets = [
        [pcb_hole_inset, pcb_hole_inset],
        [pcb_w - pcb_hole_inset, pcb_hole_inset],
        [pcb_hole_inset, pcb_d - pcb_hole_inset],
        [pcb_w - pcb_hole_inset, pcb_d - pcb_hole_inset],
    ];
    for (p = offsets) children(p[0], p[1]);
}

module bracket_ears() {
    // Two ears on the sides for mounting to the machine
    for (side = [0, 1]) {
        mirror([side, 0, 0])
        translate([-bracket_ear_w, outer_d / 2 - bracket_ear_w / 2, 0]) {
            difference() {
                cube([bracket_ear_w, bracket_ear_w, bracket_ear_h]);
                translate([bracket_ear_w / 2, bracket_ear_w / 2, -0.1])
                    cylinder(h = bracket_ear_h + 0.2, d = bracket_hole_d, $fn = 24);
            }
        }
    }
}

// --- Base / tray ---
module base() {
    difference() {
        union() {
            // Main box
            cube([outer_w, outer_d, total_h]);

            // Mounting ears
            translate([0, 0, 0]) bracket_ears();
            translate([outer_w, 0, 0]) bracket_ears();
        }

        // Hollow out the inside (above the base plate)
        translate([wall, wall, base_thick])
            cube([inner_w, inner_d, total_h]);

        // Pin header cutout on one side
        translate([wall + tolerance + inner_w/2 - 12, -0.1, base_thick + post_h - 0.5])
            cube([24, wall + 0.2, pcb_thick + lip_height + 1]);
    }

    // Standoffs at PCB mounting hole positions
    pcb_screw_positions() standoff($children > 0 ? 0 : 0, 0);

    // Manual standoffs since children() trick doesn't work easily in OpenSCAD
    standoff(pcb_hole_inset, pcb_hole_inset);
    standoff(pcb_w - pcb_hole_inset, pcb_hole_inset);
    standoff(pcb_hole_inset, pcb_d - pcb_hole_inset);
    standoff(pcb_w - pcb_hole_inset, pcb_d - pcb_hole_inset);
}

// --- Faceplate (optional snap-on lid) ---
module faceplate() {
    difference() {
        // Outer plate
        cube([outer_w, outer_d, 2.0]);

        // Antenna window
        translate([outer_w/2 - antenna_w/2, outer_d/2 - antenna_d/2, -0.1])
            cube([antenna_w, antenna_d, 2.2]);

        // Screw holes to match PCB standoffs
        translate([wall + tolerance + pcb_hole_inset, wall + tolerance + pcb_hole_inset, -0.1])
            cylinder(h = 2.2, d = screw_d, $fn = 20);
        translate([wall + tolerance + pcb_w - pcb_hole_inset, wall + tolerance + pcb_hole_inset, -0.1])
            cylinder(h = 2.2, d = screw_d, $fn = 20);
        translate([wall + tolerance + pcb_hole_inset, wall + tolerance + pcb_d - pcb_hole_inset, -0.1])
            cylinder(h = 2.2, d = screw_d, $fn = 20);
        translate([wall + tolerance + pcb_w - pcb_hole_inset, wall + tolerance + pcb_d - pcb_hole_inset, -0.1])
            cylinder(h = 2.2, d = screw_d, $fn = 20);
    }

    // Label
    translate([outer_w/2, outer_d - 3, 2.0])
        linear_extrude(0.4)
            text("NFC", size = 6, halign = "center", font = "Liberation Sans:style=Bold");
}

// --- Render ---
// Uncomment one at a time for export:

// Base tray
base();

// Faceplate (shifted to the side for preview)
translate([outer_w + 10, 0, 0])
    faceplate();

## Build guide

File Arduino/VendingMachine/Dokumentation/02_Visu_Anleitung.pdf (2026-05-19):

# Snackomat - Visualisierung in Automation Studio

Diese Anleitung fuehrt Schritt fuer Schritt durch die Visu-Erstellung. Voraussetzung: Du hast das Projekt Swiity_GruppeC.apj in Automation Studio 4.12 geoeffnet und der Quellcode (Global.typ, Program/Cyclic.cpp etc.) ist vorhanden. Die Visu-Seiten wurden als Skelett angelegt - du musst sie jetzt in AS mit Widgets fuellen.
Hinweis: Sichere das Projekt vor der Bearbeitung (z.B. ganzen Ordner als ZIP kopieren). Die .page-Dateien sind XML - wenn etwas schief geht, kann eine Seite nicht mehr geoeffnet werden.

## 1. Projekt bauen (Testlauf)

Bevor du die Visu baust, stelle sicher dass die Logik kompiliert:
1 AS oeffnen, Projekt Swiity_GruppeC.apj laden.
2 Im Projektbaum Rechtsklick auf Configuration Config1 -> Build Configuration. 3 Output-Fenster beobachten - keine roten Fehler, nur ggf. Warnungen.
4 Bei 'Library AsTCP not found' -> siehe Abschnitt 2.1.

### 2.1 Fehlende Libraries hinzufuegen

Im Projektbaum unter Logical / Libraries:
1 Rechtsklick -> Add Object -> Existing Library.
2 Aus der Liste auswaehlen und je per Doppelklick hinzufuegen: AsTCP, AsString, AsBrStr, AsIOTime. 3 Die jeweiligen Version koennen Defaults bleiben. Auf F7 (Build) pruefen.

## 2. Visu-Seiten-Uebersicht

Im Projekt sind bereits folgende Seiten angelegt (Ordner Logical/Visu/Pages/):

Datei | Index Zweck | | Was du einbauen musst
_00_Init.page | 0 | Start/Logo | bereits fertig von Vorlage
_10_Main.page | 10 | Produktauswahl (4 Fach-Buttons) | Buttons + Fach-Anzeigen
_20_BarBezahlen.page | 20 | Muenzzaehler + Bestaetigen | Anzeige, Bestaetigen-Button
_30_KarteBezahlen.page | 30 | Karte auflegen | Symbol, Status, Bestaetigen
_40_Ausgabe.page | 40 | Motor laeuft - Fortschritt | Fortschrittsbalken
_50_Danke.page | 50 | Dankeschoen | Text, 'Zurueck'-Button
_90_Fehler.page | 90 | Fehler/Leer | Meldung, 'Zurueck'
_900_Settings.page | 900 | Einstellungen | von Vorlage - behalten
_910_Settings1.page | 910 | Motor-Kalibrierung | Buttons P910_Kalibriere1-4

## 3. Schritt-fuer-Schritt: Seite _10_Main.page bauen

Diese Seite ist das Herz der Bedienung. Sie zeigt 4 Produkte mit Preis/Bestand und ermoeglicht die Auswahl.

### 3.1 Seite oeffnen

Im Projektbaum unter Logical/Visu/Pages/ Doppelklick auf _10_Main.page. Der Layout-Editor oeffnet sich.

### 3.2 Vier Produkt-Buttons erstellen

Wir brauchen 4 grosse Buttons, 2x2 Raster.
1 Toolbox (rechts) -> Button auswaehlen.
2 Rechteck aufziehen: Position links 50, oben 100, Breite 320, Hoehe 150.
3 In den Properties (unten) Name setzen: btnFach1.
4 Property Text -> '%s' und im Punkt TextDataPoint binden auf: ::AsGlobalPV:gFach[0].name.
5 Property ActionDatapoint -> ::AsGlobalPV:Visu.buttons.P10_Selection1. Action-Type: Pushbutton (setzt beim Klick auf 1 und die PLC loescht zurueck).
6 Button kopieren (Strg+C / Strg+V) und Kopien positionieren: btnFach2 (rechts daneben, P10_Selection2), btnFach3 (unten links, P10_Selection3), btnFach4 (unten rechts, P10_Selection4).

### 3.3 Bestand/Preis unter jedem Button anzeigen

1 Toolbox -> Numeric Output.
2 Neben btnFach1 platzieren (oder als Label darueber).
3 Property DataPoint: ::AsGlobalPV:gFach[0].preisCent. Format: 'Preis: %3d Cent'.
4 Zweites Numeric Output darunter: DataPoint ::AsGlobalPV:gFach[0].abstandCm, Format 'Bestand: %2d cm'.
5 Drittes Feld: Text Output mit Status VOLL/LEER. Property Text: '%s' Format, Variable: ::AsGlobalPV:gFach[0].istLeer (BOOL -> Text wird zur Auswahl 'VOLL' / 'LEER' ueber Textgroup).
6 Alles fuer Fach 2-4 wiederholen (je Index 2, 3, 4).

### 3.4 Abbrechen-Button (oben rechts)

Kleiner Button 'Abbrechen' mit ActionDatapoint ::AsGlobalPV:Visu.buttons.PXX_Abbrechen - wird nur sichtbar, wenn Visu.page.actpage > 0 (Visibility-Expression).

## 4. Seite _20_BarBezahlen.page bauen

1 Ueberschrift: Text Output 'Bitte Muenzen einwerfen'.
2 Gross in der Mitte: Numeric Output gCoin.summeCent, Format 'Eingezahlt: %3d Cent'.
3 Darunter: Numeric Output gSel.preisCent, Format 'Preis: %3d Cent'.
4 Fortschritt: Progress Bar EndValue = gSel.preisCent, Value = gCoin.summeCent.
5 Button 'Bestaetigen': ActionDatapoint Visu.buttons.P20_BestaetigeBar, Enable-Expression: gCoin.summeCent >= gSel.preisCent.
6 Button 'Abbrechen': ActionDatapoint Visu.buttons.PXX_Abbrechen.

## 5. Seite _30_KarteBezahlen.page bauen (NFC)

Das Herzstueck der Karten-Zahlung. Grosses Symbol, das auf die Stelle zeigt wo der PN532-Sensor hinter dem Display montiert ist.
1 Ueberschrift: 'Karte hier auflegen'
2 Gross in der Mitte: ein Bitmap-Control (Pfeil/Karten-Symbol) das nach unten auf den NFC-Spot zeigt. Vorbereitete Bitmap unter Bitmaps/NfcSymbol.bminfo anlegen (Import von Vorlage/Internet).
3 Status-Textanzeige: Text Output mit DataPoint gNfc.uidHex. Format: 'UID: %s'.
4 Ampel-Anzeige: Drei Texte/Bitmaps die je nach Bedingung sichtbar sind:
- 'Warte auf Karte...' wenn gNfc.erkannt = 0
- 'Karte akzeptiert' wenn gNfc.erkannt=1 AND gNfc.inWhitelist=1
- 'Karte unbekannt' wenn gNfc.erkannt=1 AND gNfc.inWhitelist=0
5 Button 'Bestaetigen': ActionDatapoint Visu.buttons.P30_BestaetigeKarte, Enable: gNfc.inWhitelist = 1. 6 Button 'Abbrechen': ActionDatapoint Visu.buttons.PXX_Abbrechen.

## 6. Seite _40_Ausgabe, _50_Danke, _90_Fehler

Einfach aufgebaut:
1 _40: Text 'Bitte entnehmen Sie Ihr Produkt' + Progress Bar von 0..100. 2 _50: Text 'Danke!' + Auto-Weiter nach 3 s (erledigt die PLC).
3 _90: Roter Hintergrund, Text 'Fehler - bitte kontaktieren Sie Personal'.

## 7. Seite _910_Settings1 - Kalibrierung

Auf der Settings-Seite 1 Kalibrier-Buttons fuer jedes Fach:
1 Button 'Fach 1 kalibrieren' -> ActionDatapoint Visu.buttons.P910_Kalibriere1.
2 Gleich fuer Fach 2, 3, 4.
3 Wenn gedrueckt: PLC sendet C:n an ESP32 -> ESP32 misst den aktuellen Abstand und speichert ihn als 'VOLL'-Referenz in NVS.

## 8. Projekt bauen + Simulator testen

1 F7 oder Menue Project -> Build Configuration.
2 Wenn 0 Fehler: Configuration -> Simulation starten (ARsim).
3 Im Simulator sollte die _00_Init-Seite 3 s sichtbar sein, dann automatischer Wechsel auf _10_Main.
4 Tippe auf einen Fach-Button -> Wechsel auf _10 -> Bar/Karte-Auswahl. Bar-Button -> _20. Du kannst mit dem 'Muenzeinwurf-Simulator' ::AsGlobalPV:diMuenzeinwurf auf TRUE/FALSE togglen.

## 9. Live-Test mit Claude MCP

Mit dem installierten br-automation-mcp Server kannst du mich bitten:

"Bau das Projekt und starte den Simulator"
"Schreib 1 auf die Variable Visu.buttons.P10_Selection1"
"Lies gFach[0].istLeer"
"Setze gCoin.summeCent auf 200 und druecke P20_BestaetigeBar"
So kannst du ganze Testsequenzen ohne Handkontakt zum Touchscreen durchspielen.

## 10. Was noch? (optional)

Wenn alles laeuft, kannst du die Visu noch verschoenern:
1 Sprachumschaltung (Deutsch/Englisch) ueber Visu.settings.Language (schon vorbereitet in Vorlage). 2 Preise in der Settings-Seite editierbar: Numeric Input auf Perm_preisCent[n].
3 Alarm/Log-Seite fuer ESP32-Fehler - filtere ERR:-Nachrichten aus gEsp.letzteNachricht.
4 Screensaver nach 60 s Inaktivitaet.

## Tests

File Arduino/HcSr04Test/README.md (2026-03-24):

# HC-SR04 ESP32 Test Project

This folder contains a test sketch for reading an HC-SR04 ultrasonic sensor with an ESP32 and displaying the data on a web dashboard. It also includes functionality to toggle a component (the onboard LED) via the web interface.

## Hardware Required
- **ESP32 Development Board**
- **HC-SR04 Ultrasonic Sensor**

## Pinout
- **HC-SR04 Trig Pin**: GPIO 5
- **HC-SR04 Echo Pin**: GPIO 18
- **LED/Control Pin**: GPIO 2 (ESP32 Onboard LED)

*Note: The HC-SR04 requires a 5V supply and outputs 5V. To prevent damage to the ESP32 (which is 3.3V tolerant on some boards but strictly 3.3V on most), use a voltage divider on the Echo pin if required.*

## Setup Instructions
1. Open `HcSr04Test.ino` in the Arduino IDE (or PlatformIO).
2. Change the `ssid` and `password` variables to match your Wi-Fi network.
3. Flash the code to your ESP32.
4. Open the Serial Monitor (115200 baud) to find the ESP32's IP address.
5. Enter the IP address in a web browser to access the Web Dashboard.

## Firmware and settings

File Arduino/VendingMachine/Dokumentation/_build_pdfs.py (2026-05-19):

"""
Erzeugt die zwei Dokumentations-PDFs fuer das Snackomat-Projekt.
Ausfuehren mit: python _build_pdfs.py
"""
from pathlib import Path
from reportlab.lib.pagesizes import A4
from reportlab.platypus import (
    SimpleDocTemplate, Paragraph, Spacer, Table, TableStyle,
    PageBreak, ListFlowable, ListItem,
)
from reportlab.lib.styles import getSampleStyleSheet, ParagraphStyle
from reportlab.lib import colors
from reportlab.lib.units import cm

OUT_DIR = Path(__file__).parent

# --- Styles -----------------------------------------------------------
styles = getSampleStyleSheet()
styles.add(ParagraphStyle(name="H1Ger", parent=styles["Heading1"],
           fontSize=18, textColor=colors.HexColor("#1a5276"), spaceBefore=12, spaceAfter=8))
styles.add(ParagraphStyle(name="H2Ger", parent=styles["Heading2"],
           fontSize=14, textColor=colors.HexColor("#2e86c1"), spaceBefore=10, spaceAfter=6))
styles.add(ParagraphStyle(name="H3Ger", parent=styles["Heading3"],
           fontSize=11, textColor=colors.HexColor("#154360"), spaceBefore=8, spaceAfter=4))
styles.add(ParagraphStyle(name="Body", parent=styles["BodyText"],
           fontSize=10, leading=13, spaceAfter=4))
styles.add(ParagraphStyle(name="Warn", parent=styles["BodyText"],
           fontSize=10, leading=13, backColor=colors.HexColor("#fdebd0"),
           borderColor=colors.HexColor("#ca6f1e"), borderWidth=1, borderPadding=6, spaceAfter=6))
styles.add(ParagraphStyle(name="Note", parent=styles["BodyText"],
           fontSize=10, leading=13, backColor=colors.HexColor("#eaf2f8"),
           borderColor=colors.HexColor("#2e86c1"), borderWidth=1, borderPadding=6, spaceAfter=6))
styles.add(ParagraphStyle(name="CodeBlk", parent=styles["Code"],
           fontName="Courier", fontSize=9, leading=11, backColor=colors.HexColor("#f4f6f6"),
           borderPadding=4, leftIndent=6, rightIndent=6))

def H1(t): return Paragraph(t, styles["H1Ger"])
def H2(t): return Paragraph(t, styles["H2Ger"])
def H3(t): return Paragraph(t, styles["H3Ger"])
def P(t):  return Paragraph(t, styles["Body"])
def N(t):  return Paragraph("<b>Hinweis:</b> " + t, styles["Note"])
def W(t):  return Paragraph("<b>Achtung:</b> " + t, styles["Warn"])
def C(t):  return Paragraph(t.replace("\n","<br/>"), styles["CodeBlk"])

def make_table(header, rows, col_widths=None):
    data = [header] + rows
    t = Table(data, colWidths=col_widths, repeatRows=1)
    t.setStyle(TableStyle([
        ("BACKGROUND", (0,0), (-1,0), colors.HexColor("#2e86c1")),
        ("TEXTCOLOR",  (0,0), (-1,0), colors.white),
        ("FONTNAME",   (0,0), (-1,0), "Helvetica-Bold"),
        ("FONTSIZE",   (0,0), (-1,-1), 9),
        ("BOTTOMPADDING",(0,0), (-1,0), 6),
        ("GRID", (0,0), (-1,-1), 0.5, colors.grey),
        ("ROWBACKGROUNDS", (0,1), (-1,-1),
            [colors.whitesmoke, colors.HexColor("#f4f6f6")]),
        ("VALIGN", (0,0), (-1,-1), "MIDDLE"),
    ]))
    return t

# ======================================================================
#  PDF 1: VERKABELUNG
# ======================================================================

def build_verkabelung_pdf():
    doc = SimpleDocTemplate(str(OUT_DIR / "01_Verkabelung.pdf"),
        pagesize=A4, leftMargin=1.8*cm, rightMargin=1.8*cm,
        topMargin=1.8*cm, bottomMargin=1.8*cm,
        title="Snackomat Verkabelung", author="Swiity Gruppe C")
    s = []

    s.append(H1("Snackomat - Verkabelung &amp; Inbetriebnahme"))
    s.append(P("Berufsschulprojekt Gruppe C (Swiity). "
               "Diese Anleitung fuehrt Schritt fuer Schritt durch den Aufbau."))

    s.append(H2("1. Uebersicht"))
    s.append(P("Der Automat besteht aus zwei intelligenten Einheiten:"))
    s.append(P("- <b>B&amp;R X20CP1382 + 6PPT50 Panel</b> (Touchscreen + SPS) - "
               "bedient die Visualisierung, zaehlt Muenzen und schaltet das Freigaberelais."))
    s.append(P("- <b>ESP32</b> - liest die 4 HC-SR04 Fuellstandssensoren, den "
               "PN532 NFC-Leser und steuert die 4 DC-Motoren ueber Relais."))
    s.append(P("Die beiden Einheiten kommunizieren <b>ueber LAN (TCP/IP, Port 8000)</b>. "
               "Der ESP32 verbindet sich als Client zur PLC-IP 192.168.2.20."))

    s.append(H2("2. Benoetigte Teile (Stueckliste)"))
    s.append(make_table(
        ["Pos", "Bauteil", "Menge", "Anmerkung"],
        [["1", "ESP32 DevKit (30 Pin)",             "1", "mit USB-C oder Micro-USB"],
         ["2", "HC-SR04 Ultraschall-Sensor",        "4", "5V Versorgung!"],
         ["3", "Relais-Modul 4-Kanal 5V",           "1", "active HIGH"],
         ["4", "DC-Getriebemotor 12V",              "4", "je Fach einer"],
         ["5", "PN532 NFC-Modul",                   "1", "im I2C-Modus"],
         ["6", "X20CP1382 CPU",                    "1", "bereits vorhanden"],
         ["7", "6PPT50.0502-10A Panel",            "1", "Touchscreen, VNC auf 5900"],
         ["8", "X20DI (X1) - Muenzeinwurf",        "1", "Lichtschranke DI01"],
         ["9", "X20DO (X3) - 4x Motor + LED",      "1", "DO01-DO04 Motoren, DO05 LED"],
         ["10", "X20AO2622 Motor-Speed (Analog)",  "1", "Geschwindigkeit 0-10V"],
         ["11", "Lichtschranke (1-Kanal)",           "1", "Muenzkanal"],
         ["12", "Netzteil 5V 3A",                   "1", "fuer ESP32+Relais+HC-SR04"],
         ["13", "Netzteil 12V 5A",                  "1", "fuer DC-Motoren"],
         ["14", "Reihenklemmen Weidmueller ZDK 2,5", "ca. 30", ""],
         ["15", "LAN-Kabel (Cat5 oder besser)",     "2", "1x X20CP1382, 1x ESP32 (via Router)"],
         ["16", "Ethernet-Router/Switch",           "1", "WLAN + LAN gemeinsam"],
         ["17", "Jumperkabel/Lappkabel div.",       "-", ""],
         ],
        col_widths=[1.2*cm, 6.5*cm, 1.5*cm, 6.8*cm]))

    s.append(PageBreak())
    s.append(H2("3. Pin-Belegung ESP32"))

    s.append(H3("3.1 HC-SR04 Ultraschallsensoren"))
    s.append(make_table(
        ["Fach", "TRIG (GPIO)", "ECHO (GPIO)", "VCC", "GND"],
        [["1", "26", "27", "5V", "GND"],
         ["2", "14", "12", "5V", "GND"],
         ["3", "33", "32", "5V", "GND"],
         ["4", "25", "35", "5V", "GND"]]))
    s.append(W("HC-SR04 braucht <b>5V</b> - an 3,3V antwortet er nicht oder falsch. "
               "ECHO liefert zwar 5V-Pegel, der ESP32 vertraegt das an den "
               "gewaehlten Input-Pins, aber sicherheitshalber einen 1k/2k "
               "Spannungsteiler einbauen, wenn du auf Nummer sicher gehen willst."))

    s.append(H3("3.2 Relais-Modul (Motorsteuerung)"))
    s.append(make_table(
        ["Relais", "Steuer-Pin (GPIO)", "Last (Motor an NO/COM)"],
        [["IN1 - Motor Fach 1", "16", "12V + Motor 1"],
         ["IN2 - Motor Fach 2", "17", "12V + Motor 2"],
         ["IN3 - Motor Fach 3", "18", "12V + Motor 3"],
         ["IN4 - Motor Fach 4", "19", "12V + Motor 4"]]))
    s.append(P("Versorgung Relais-Modul: <b>VCC = 5V</b> (ESP32-Netzteil), "
               "<b>GND = GND</b>. Zusaetzlich Jumper <b>JD-VCC</b> oeffnen "
               "und auf <b>12V</b> des Motor-Netzteils legen (Optokoppler-Trennung)."))
    s.append(W("5V und 12V GND muessen verbunden sein (gemeinsame Masse), "
               "sonst schaltet das Relais nicht. <b>Aber</b>: niemals 5V+ und 12V+ "
               "verbinden!"))

    s.append(H3("3.3 PN532 NFC-Modul (I2C)"))
    s.append(make_table(
        ["PN532 Pin", "ESP32 Pin", "Anmerkung"],
        [["VCC", "3V3", "NICHT 5V!"],
         ["GND", "GND", ""],
         ["SDA", "GPIO 21", "I2C Daten"],
         ["SCL", "GPIO 22", "I2C Takt"],
         ["IRQ", "GPIO 13", "Interrupt"],
         ["RST", "GPIO 15", "Reset"]]))
    s.append(W("Am PN532-Modul gibt es DIP-Schalter fuer den Modus. "
               "Fuer unser Setup muss <b>I2C</b> aktiv sein: "
               "SEL0 = AUS (OFF), SEL1 = EIN (ON)."))

    s.append(PageBreak())
    s.append(H2("4. Verdrahtung X20CP1382 &amp; X20-Module"))
    s.append(N("Die Hardware-Konfiguration kommt aus dem Schul-Basisprojekt "
               "und ist bereits im AS-Projekt angelegt (IoMap.iom). "
               "Die Klemmen-Bezeichnungen hier entsprechen dem AS-Projekt."))

    s.append(H3("4.1 Lichtschranke am Muenzkanal (Modul X1)"))
    s.append(make_table(
        ["Signal", "X1 Klemme", "AS-Variable"],
        [["+24V (Versorgung Lichtschranke)", "24V+", "-"],
         ["Ausgang Lichtschranke (Signal)", "DI 01", "diMuenzeinwurf"],
         ["GND", "GND", "-"]]))
    s.append(N("Die Muenz-Zaehlung erfolgt im Task <i>Program1</i> in "
               "<i>Logical/Program1/Cyclic.cpp</i>. Zaehler: "
               "<b>gCoin.summeCent</b> (jeder Impuls = <b>gCoin.wertProImpulsCent</b>, "
               "Default 10 Cent)."))

    s.append(H3("4.2 Motoren + LED am Digital-Output (Modul X3)"))
    s.append(make_table(
        ["Signal", "X3 Klemme", "AS-Variable"],
        [["Motor Fach 1", "DO 01", "doMotor[0]"],
         ["Motor Fach 2", "DO 02", "doMotor[1]"],
         ["Motor Fach 3", "DO 03", "doMotor[2]"],
         ["Motor Fach 4", "DO 04", "doMotor[3]"],
         ["LED-Beleuchtung", "DO 05", "doLedEin"]]))
    s.append(N("doMotor[] wird von der PLC als <b>Fallback</b> genutzt, falls "
               "ESP32 nicht verbunden ist. Im Normalbetrieb steuert der ESP32 "
               "die Motoren ueber seine eigenen Relais (siehe Abschnitt 3.2)."))

    s.append(H3("4.3 Motor-Speed Analog (Modul X20AO2622)"))
    s.append(P("Optional: Analog-Output fuer variable Motor-Geschwindigkeit. "
               "Variable <b>aoMotorspeed</b> (0-32767 = 0-10V)."))

    s.append(H3("4.4 Ethernet / Netzwerk"))
    s.append(P("Die X20CP1382 hat <b>IP 192.168.2.20</b> (siehe Cpu.pkg). "
               "ESP32 muss im gleichen Subnetz sein. Empfehlung: Router "
               "mit DHCP auf 192.168.2.x konfigurieren, ESP32 bekommt dann "
               "automatisch eine IP."))
    s.append(make_table(
        ["Geraet", "Anschluss", "Ziel"],
        [["X20CP1382 CPU", "ETH1", "Switch/Router"],
         ["6PPT50 Panel",  "ETH",  "gleicher Switch (VNC ueber Panel)"],
         ["ESP32",         "WLAN", "gleicher Router"],
         ["Laptop (Entwicklung)", "LAN/WLAN", "gleicher Router (fuer AS + ESP32-Upload)"]]))

    s.append(PageBreak())
    s.append(H2("5. Stromversorgung"))
    s.append(make_table(
        ["Verbraucher", "Spannung", "Max. Strom", "Quelle"],
        [["ESP32 + HC-SR04 + Relais-Spulen", "5V", "~1,5 A", "Netzteil 1 (5V 3A)"],
         ["PN532 NFC-Modul",                  "3,3V", "~0,1 A", "ESP32 3V3 Pin"],
         ["DC-Motoren (ueber Relais)",        "12V",  "je ~1 A", "Netzteil 2 (12V 5A)"],
         ["Lichtschranke",                     "24V", "0,05 A", "X20 Powersupply oder 24V NT"],
         ["X20CP1382 + 6PPT50 Panel",          "24V", "~1,5 A", "Panel-Netzteil"]]))
    s.append(W("<b>Alle Massen (GND) miteinander verbinden</b> - sonst gibt es "
               "unvorhersagbares Verhalten. Ausnahme: 24V-Bereich der PLC darf "
               "galvanisch getrennt bleiben, muss dann aber ueber Relais/Koppler "
               "laufen."))

    s.append(H2("6. Aufbau Schritt fuer Schritt"))
    steps = [
        "Alle Netzteile <b>ausschalten</b>.",
        "Reihenklemmen-Leiste montieren (Weidmueller ZDK 2,5).",
        "5V-Netzteil an ESP32 (Vin oder 5V Pin) anschliessen. GND nicht vergessen.",
        "HC-SR04-Sensoren 1-4 an die jeweiligen GPIO-Pins (siehe Tabelle 3.1) klemmen.",
        "Relais-Modul an 5V/GND + IN1-IN4. JD-VCC-Jumper abziehen, JD-VCC an 12V-Netzteil+.",
        "DC-Motoren an NO+COM der Relais-Kontakte. 12V+ an COM, Motor zwischen NO und 12V-.",
        "PN532 an 3V3/GND, SDA=21, SCL=22, IRQ=13, RST=15. DIP-Schalter I2C.",
        "Lichtschranke an X20 Modul X1 DI01 + 24V Versorgung.",
        "X20CP1382 + 6PPT50 Panel ueber Ethernet an Switch/Router. 24V-Netzteil an "
        "die oberen Klemmen (24V/GND).",
        "Netzteile nacheinander einschalten: zuerst 24V (PLC), dann 5V (ESP32), "
        "zuletzt 12V (Motoren).",
        "Panel bootet (AR G4.83). ESP32 bootet via USB-Power, wenn angesteckt. "
        "Im normalen Betrieb laeuft ESP32 ueber 5V-Netzteil.",
    ]
    s.append(ListFlowable(
        [ListItem(P(st)) for st in steps],
        bulletType="1", start="1"))

    s.append(PageBreak())
    s.append(H2("7. Erstes Hochfahren - Checkliste"))
    s.append(make_table(
        ["Nr", "Schritt", "Erwartung"],
        [["1", "ESP32 an Arduino IDE, Serial Monitor 115200", "Boot-Meldung 'Snackomat ESP32-Firmware'"],
         ["2", "config.h: WIFI_SSID und WIFI_PASSWORD anpassen",
                "Upload erfolgreich"],
         ["3", "Serial: WLAN verbinde... -> verbunden. IP: ...", "innerhalb 20 s"],
         ["4", "Serial: TCP verbinde zu 192.168.2.20:8000", "'TCP-Verbindung zur PLC steht'"],
         ["5", "PLC: Variable <b>gEsp.verbunden</b> via OPC-UA", "TRUE"],
         ["6", "Variable <b>Visu.page.actpage</b>", "0 (Init) oder 10 (Main)"],
         ["7", "Muenze einwerfen - <b>gCoin.summeCent</b>", "erhoeht sich um Wert pro Impuls (Default 10)"],
         ["8", "Karte an PN532 halten - <b>gNfc.uidHex</b>",
                "HEX-UID erscheint, gNfc.inWhitelist pruefen"]]))
    s.append(N("Zum Live-Testen per Claude MCP: sag einfach <i>'Lies die Variable "
               "Visu.page.actpage aus der PLC'</i>, dann wird per OPC-UA abgefragt."))

    s.append(H2("8. Troubleshooting"))
    s.append(make_table(
        ["Problem", "Ursache", "Fix"],
        [["ESP32 rebootet endlos", "Watchdog oder fehlende Lib", "Serial-Log pruefen"],
         ["HC-SR04 misst -1", "falsche Spannung (3,3V statt 5V)", "auf 5V umklemmen"],
         ["Relais klickt nicht", "GND nicht verbunden", "5V-GND und 12V-GND bruecken"],
         ["TCP verbindet nicht", "falsche IP oder PLC nicht aktiv",
                                  "in config.h PLC_IP pruefen, 'ping 192.168.2.20'"],
         ["PN532 nicht erkannt", "I2C DIP-Schalter falsch", "SEL0 OFF, SEL1 ON setzen"],
         ["Muenze zaehlt nicht", "Lichtschranke prellt",
                                  "Entprellzeit in Program1 Variables.var (entprellungMs) erhoehen"],
         ["Motor laeuft zu kurz/lang", "MOTOR_LAUFZEIT_DEFAULT_MS",
                                  "in config.h anpassen oder per OPC-UA Perm_motorLaufzeit[n] setzen"]]))

    doc.build(s)
    print("OK:", OUT_DIR / "01_Verkabelung.pdf")


# ======================================================================
#  PDF 2: VISU-ANLEITUNG (Klick-fuer-Klick)
# ======================================================================

def build_visu_pdf():
    doc = SimpleDocTemplate(str(OUT_DIR / "02_Visu_Anleitung.pdf"),
        pagesize=A4, leftMargin=1.8*cm, rightMargin=1.8*cm,
        topMargin=1.8*cm, bottomMargin=1.8*cm,
        title="Snackomat Visu-Anleitung", author="Swiity Gruppe C")
    s = []

    s.append(H1("Snackomat - Visualisierung in Automation Studio"))
    s.append(P("Diese Anleitung fuehrt Schritt fuer Schritt durch die Visu-Erstellung. "
               "Voraussetzung: Du hast das Projekt <b>Swiity_GruppeC.apj</b> in Automation "
               "Studio 4.12 geoeffnet und der Quellcode (Global.typ, Program/Cyclic.cpp etc.) "
               "ist vorhanden. Die Visu-Seiten wurden als Skelett angelegt - du musst sie jetzt "
               "in AS mit Widgets fuellen."))

    s.append(N("Sichere das Projekt vor der Bearbeitung (z.B. ganzen Ordner als ZIP kopieren). "
               "Die .page-Dateien sind XML - wenn etwas schief geht, kann eine Seite nicht "
               "mehr geoeffnet werden."))

    s.append(H2("1. Projekt bauen (Testlauf)"))
    s.append(P("Bevor du die Visu baust, stelle sicher dass die Logik kompiliert:"))
    s.append(ListFlowable([
        ListItem(P("AS oeffnen, Projekt Swiity_GruppeC.apj laden.")),
        ListItem(P("Im Projektbaum Rechtsklick auf Configuration <b>Config1</b> -> <i>Build Configuration</i>.")),
        ListItem(P("Output-Fenster beobachten - keine roten Fehler, nur ggf. Warnungen.")),
        ListItem(P("Bei 'Library AsTCP not found' -> siehe Abschnitt 2.1.")),
    ], bulletType="1"))

    s.append(H3("2.1 Fehlende Libraries hinzufuegen"))
    s.append(P("Im Projektbaum unter <b>Logical / Libraries</b>:"))
    s.append(ListFlowable([
        ListItem(P("Rechtsklick -> <i>Add Object -> Existing Library</i>.")),
        ListItem(P("Aus der Liste auswaehlen und je per Doppelklick hinzufuegen: "
                   "<b>AsTCP</b>, <b>AsString</b>, <b>AsBrStr</b>, <b>AsIOTime</b>.")),
        ListItem(P("Die jeweiligen Version koennen Defaults bleiben. Auf F7 (Build) pruefen.")),
    ], bulletType="1"))

    s.append(H2("2. Visu-Seiten-Uebersicht"))
    s.append(P("Im Projekt sind bereits folgende Seiten angelegt (Ordner "
               "<b>Logical/Visu/Pages/</b>):"))
    s.append(make_table(
        ["Datei", "Index", "Zweck", "Was du einbauen musst"],
        [["_00_Init.page", "0", "Start/Logo", "bereits fertig von Vorlage"],
         ["_10_Main.page", "10", "Produktauswahl (4 Fach-Buttons)", "Buttons + Fach-Anzeigen"],
         ["_20_BarBezahlen.page", "20", "Muenzzaehler + Bestaetigen", "Anzeige, Bestaetigen-Button"],
         ["_30_KarteBezahlen.page", "30", "Karte auflegen", "Symbol, Status, Bestaetigen"],
         ["_40_Ausgabe.page", "40", "Motor laeuft - Fortschritt", "Fortschrittsbalken"],
         ["_50_Danke.page", "50", "Dankeschoen", "Text, 'Zurueck'-Button"],
         ["_90_Fehler.page", "90", "Fehler/Leer", "Meldung, 'Zurueck'"],
         ["_900_Settings.page", "900", "Einstellungen", "von Vorlage - behalten"],
         ["_910_Settings1.page", "910", "Motor-Kalibrierung", "Buttons P910_Kalibriere1-4"]],
        col_widths=[4.2*cm, 1.0*cm, 5.0*cm, 6.0*cm]))

    s.append(PageBreak())
    s.append(H2("3. Schritt-fuer-Schritt: Seite _10_Main.page bauen"))
    s.append(P("Diese Seite ist das <b>Herz</b> der Bedienung. Sie zeigt 4 Produkte mit "
               "Preis/Bestand und ermoeglicht die Auswahl."))

    s.append(H3("3.1 Seite oeffnen"))
    s.append(P("Im Projektbaum unter <i>Logical/Visu/Pages/</i> Doppelklick auf "
               "<b>_10_Main.page</b>. Der Layout-Editor oeffnet sich."))

    s.append(H3("3.2 Vier Produkt-Buttons erstellen"))
    s.append(P("Wir brauchen 4 grosse Buttons, 2x2 Raster."))
    s.append(ListFlowable([
        ListItem(P("Toolbox (rechts) -> <b>Button</b> auswaehlen.")),
        ListItem(P("Rechteck aufziehen: <i>Position</i> links 50, oben 100, "
                   "Breite 320, Hoehe 150.")),
        ListItem(P("In den Properties (unten) <b>Name</b> setzen: "
                   "<b>btnFach1</b>.")),
        ListItem(P("Property <b>Text</b> -> '%s' und im Punkt <b>TextDataPoint</b> "
                   "binden auf: <i>::AsGlobalPV:gFach[0].name</i>.")),
        ListItem(P("Property <b>ActionDatapoint</b> -> "
                   "<i>::AsGlobalPV:Visu.buttons.P10_Selection1</i>. "
                   "Action-Type: <b>Pushbutton</b> "
                   "(setzt beim Klick auf 1 und die PLC loescht zurueck).")),
        ListItem(P("Button kopieren (Strg+C / Strg+V) und Kopien positionieren: "
                   "btnFach2 (rechts daneben, P10_Selection2), "
                   "btnFach3 (unten links, P10_Selection3), "
                   "btnFach4 (unten rechts, P10_Selection4).")),
    ], bulletType="1"))

    s.append(H3("3.3 Bestand/Preis unter jedem Button anzeigen"))
    s.append(ListFlowable([
        ListItem(P("Toolbox -> <b>Numeric Output</b>.")),
        ListItem(P("Neben btnFach1 platzieren (oder als Label darueber).")),
        ListItem(P("Property <b>DataPoint</b>: "
                   "<i>::AsGlobalPV:gFach[0].preisCent</i>. "
                   "<b>Format</b>: 'Preis: %3d Cent'.")),
        ListItem(P("Zweites Numeric Output darunter: DataPoint "
                   "<i>::AsGlobalPV:gFach[0].abstandCm</i>, Format 'Bestand: %2d cm'.")),
        ListItem(P("Drittes Feld: <b>Text Output</b> mit Status VOLL/LEER. "
                   "Property <b>Text</b>: '%s' Format, "
                   "<b>Variable</b>: <i>::AsGlobalPV:gFach[0].istLeer</i> "
                   "(BOOL -> Text wird zur Auswahl 'VOLL' / 'LEER' ueber Textgroup).")),
        ListItem(P("Alles fuer Fach 2-4 wiederholen (je Index 2, 3, 4).")),
    ], bulletType="1"))

    s.append(H3("3.4 Abbrechen-Button (oben rechts)"))
    s.append(P("Kleiner Button 'Abbrechen' mit ActionDatapoint "
               "<i>::AsGlobalPV:Visu.buttons.PXX_Abbrechen</i> - wird nur sichtbar, "
               "wenn <i>Visu.page.actpage &gt; 0</i> (Visibility-Expression)."))

    s.append(PageBreak())
    s.append(H2("4. Seite _20_BarBezahlen.page bauen"))
    s.append(ListFlowable([
        ListItem(P("Ueberschrift: <b>Text Output</b> 'Bitte Muenzen einwerfen'.")),
        ListItem(P("Gross in der Mitte: Numeric Output <b>gCoin.summeCent</b>, "
                   "Format 'Eingezahlt: %3d Cent'.")),
        ListItem(P("Darunter: Numeric Output <b>gSel.preisCent</b>, "
                   "Format 'Preis: %3d Cent'.")),
        ListItem(P("Fortschritt: <b>Progress Bar</b> EndValue = "
                   "<i>gSel.preisCent</i>, Value = <i>gCoin.summeCent</i>.")),
        ListItem(P("Button 'Bestaetigen': ActionDatapoint "
                   "<i>Visu.buttons.P20_BestaetigeBar</i>, "
                   "Enable-Expression: <i>gCoin.summeCent &gt;= gSel.preisCent</i>.")),
        ListItem(P("Button 'Abbrechen': ActionDatapoint "
                   "<i>Visu.buttons.PXX_Abbrechen</i>.")),
    ], bulletType="1"))
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

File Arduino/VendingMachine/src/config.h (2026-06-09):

// =============================================================
//  Snackomat - Zentrale Konfigurationsdatei
//  Hardware: ESP32 + 4x HC-SR04 + PN532 NFC
//  ESP32 = reiner Sensor-/NFC-Knoten. Motorsteuerung = SPS.
//  Kommunikation: 5 direkte Digitalleitungen zur B&R X20 SPS
//   GPIO16-19 -> SPS DI: Fach-Status (HIGH=VOLL, LOW=LEER)
//   GPIO23    -> SPS DI: NFC erkannt (~2s HIGH-Puls)
// =============================================================
#ifndef CONFIG_H
#define CONFIG_H

#include <Arduino.h>

// --- Debug-Ausgabe ---
#define DEBUG_MODUS     1
#define DEBUG_BAUDRATE  115200

// --- Anzahl der Faecher ---
#define ANZAHL_FAECHER  4

// =============================================================
//  PIN-BELEGUNG
// =============================================================

// HC-SR04 Ultraschall-Sensoren (Trigger = Output, Echo = Input)
#define TRIG_FACH_1  26
#define ECHO_FACH_1  27
#define TRIG_FACH_2  14
#define ECHO_FACH_2  12
#define TRIG_FACH_3  33
#define ECHO_FACH_3  32
#define TRIG_FACH_4  25
#define ECHO_FACH_4  35   // GPIO35 ist nur Input -> fuer Echo OK

// Fach-Status Ausgaenge -> SPS Digitaleingaenge
// HIGH = VOLL (Produkt vorhanden), LOW = LEER (Produkt fehlt)
#define STATUS_PIN_1  16
#define STATUS_PIN_2  17
#define STATUS_PIN_3  18
#define STATUS_PIN_4  19

// PN532 NFC-Leser (I2C)
#define PN532_SDA_PIN    21
#define PN532_SCL_PIN    22
#define PN532_IRQ_PIN    13
#define PN532_RST_PIN    15

// NFC-Erkennungs-Ausgang -> SPS Digitaleingang
// HIGH (~2s) wenn eine beliebige Karte erkannt wurde
#define NFC_OUT_PIN  23

// =============================================================
//  ZEIT- UND SCHWELLWERT-KONSTANTEN
// =============================================================
#define LEER_SCHWELLE_MM      50      // Abstand > Ref+50mm -> LEER
#define HCSR04_TIMEOUT_US     30000   // Max. 30ms auf Echo warten
#define SENSOR_INTERVALL_MS   250     // Ein Sensor alle 250ms (Round-Robin)
#define NFC_POLL_INTERVALL_MS 500     // NFC-Polling alle 500ms
#define NFC_OUT_DAUER_MS      2000    // NFC_OUT_PIN bleibt 2s HIGH

// Schallgeschwindigkeit in mm/us bei 20 °C
#define SCHALL_MM_PRO_US      0.343f

// Watchdog-Timeout (Sekunden)
#define WATCHDOG_TIMEOUT_S    10

// =============================================================
//  NVS (Preferences) Namespace
// =============================================================
#define NVS_NAMESPACE  "snackomat"

// =============================================================
//  DEBUG-MAKROS (mit Zeitstempel)
// =============================================================
#if DEBUG_MODUS
  #define DBG(x)    do { Serial.print("["); Serial.print(millis()); Serial.print("ms] "); Serial.println(x); } while(0)
  #define DBGF(...) do { Serial.print("["); Serial.print(millis()); Serial.print("ms] "); Serial.printf(__VA_ARGS__); } while(0)
#else
  #define DBG(x)
  #define DBGF(...)
#endif

#endif // CONFIG_H

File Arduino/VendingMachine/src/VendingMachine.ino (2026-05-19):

// =============================================================
//  snackomat.ino - ESP32 Snackautomat
//  Projekt: Swiity Gruppe C (Berufsschul-Projekt)
//
//  Kommunikation zur PLC: 5 direkte Digitalleitungen
//   GPIO16-19 -> PLC DI: Fach-Status (HIGH=VOLL, LOW=LEER)
//   GPIO23    -> PLC DI: NFC erkannt (~2s HIGH-Puls bei beliebiger Karte)
//
//  Flow im loop():
//   1. NfcReader  -> Karte erkennen, NFC_OUT_PIN setzen
//   2. FachManager -> Sensoren messen, STATUS_PIN_x setzen
//   3. Watchdog zuruecksetzen
// =============================================================

#include <Arduino.h>
#include <esp_task_wdt.h>

#include "config.h"
#include "hcsr04_sensor.h"
#include "preferences_manager.h"
#include "fach_manager.h"
#include "nfc_reader.h"

PreferencesManager prefsManager;
FachManager        fachManager;
NfcReader          nfcReader;

void setup() {
    Serial.begin(DEBUG_BAUDRATE);
    delay(200);

    Serial.println();
    Serial.println("================================================");
    Serial.println("  Snackomat ESP32-Firmware (Swiity Gruppe C)");
    Serial.println("  Build: " __DATE__ " " __TIME__);
    Serial.println("================================================");

    // Watchdog aktivieren -> falls loop() haengt, Reboot
    esp_task_wdt_init(WATCHDOG_TIMEOUT_S, true);
    esp_task_wdt_add(NULL);

    prefsManager.begin();
    fachManager.begin(&prefsManager);
    nfcReader.begin();

    DBG("Setup abgeschlossen - Betrieb beginnt");
}

void loop() {
    nfcReader.update();
    fachManager.update();
    esp_task_wdt_reset();
}

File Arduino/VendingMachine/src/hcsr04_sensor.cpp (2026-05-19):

// =============================================================
//  HCSR04Sensor - Implementation
// =============================================================
#include "hcsr04_sensor.h"
#include "config.h"

HCSR04Sensor::HCSR04Sensor(int fachNr, int trigPin, int echoPin)
    : fachNr(fachNr),
      trigPin(trigPin),
      echoPin(echoPin),
      letzterAbstand(-1.0f),
      referenzAbstand(-1.0f) {
}

void HCSR04Sensor::begin() {
    pinMode(trigPin, OUTPUT);
    pinMode(echoPin, INPUT);
    digitalWrite(trigPin, LOW);
    DBGF("Sensor Fach %d initialisiert (TRIG=%d, ECHO=%d)\n",
         fachNr, trigPin, echoPin);
}

// Eine einzelne Messung per pulseIn()
// Ablauf:
//   1. Trigger-Pin kurz (10 µs) auf HIGH
//   2. Echo-Pin misst die Dauer des HIGH-Impulses
//   3. Distanz = Dauer * Schallgeschwindigkeit / 2 (Hin + Rück)
float HCSR04Sensor::messeEinzeln() {
    // Trigger-Impuls (10 µs HIGH)
    digitalWrite(trigPin, LOW);
    delayMicroseconds(2);
    digitalWrite(trigPin, HIGH);
    delayMicroseconds(10);
    digitalWrite(trigPin, LOW);

    // Echo-Dauer messen, max. HCSR04_TIMEOUT_US warten
    unsigned long dauerUs = pulseIn(echoPin, HIGH, HCSR04_TIMEOUT_US);

    if (dauerUs == 0) {
        // Timeout -> nichts in Reichweite oder Fehler
        return -1.0f;
    }

    // Umrechnung in Millimeter
    float distanzMm = (dauerUs * SCHALL_MM_PRO_US) / 2.0f;
    return distanzMm;
}

// Hilfsfunktion: Median aus 3 Werten
static float median3(float a, float b, float c) {
    if ((a >= b && a <= c) || (a <= b && a >= c)) return a;
    if ((b >= a && b <= c) || (b <= a && b >= c)) return b;
    return c;
}

// Median aus 3 Messungen -> robust gegen Ausreißer
float HCSR04Sensor::messen() {
    float m1 = messeEinzeln();
    delay(15);  // Kurze Pause, damit sich Echo-Signale nicht überlagern
    float m2 = messeEinzeln();
    delay(15);
    float m3 = messeEinzeln();

    // Fehlerwerte (-1) durch Nachbarn ersetzen (best effort)
    if (m1 < 0 && m2 >= 0) m1 = m2;
    if (m3 < 0 && m2 >= 0) m3 = m2;
    if (m2 < 0 && m1 >= 0) m2 = m1;

    // Wenn alle Messungen fehlgeschlagen sind
    if (m1 < 0 && m2 < 0 && m3 < 0) {
        letzterAbstand = -1.0f;
        return -1.0f;
    }

    float ergebnis = median3(m1, m2, m3);
    letzterAbstand = ergebnis;
    return ergebnis;
}

void HCSR04Sensor::kalibrieren() {
    float gemessen = messen();
    if (gemessen > 0) {
        referenzAbstand = gemessen;
        DBGF("Sensor Fach %d kalibriert: %.1f mm\n", fachNr, referenzAbstand);
    } else {
        DBGF("Sensor Fach %d: Kalibrierung fehlgeschlagen (Timeout)\n", fachNr);
    }
}

bool HCSR04Sensor::istLeer() {
    // Ohne Kalibrierung kann kein LEER-Status bestimmt werden
    if (referenzAbstand < 0 || letzterAbstand < 0) {
        return false;
    }
    // LEER = aktueller Abstand deutlich größer als Referenz
    return (letzterAbstand > (referenzAbstand + LEER_SCHWELLE_MM));
}

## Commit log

2026-02-24 Add vending machine project template (AutomationStudio ST, Arduino, CAD, 3DPrinting, Documentation)
    [BOM_VendingMachine_v1.csv]
2026-02-24 remove BOM and Images subdirectory
    [BOM_VendingMachine_v1.csv]
2026-03-17 Add NFC module test sketch for PN532 over I2C
2026-03-18 Add KiCad schematic for NFC module I2C wiring
    [NfcModule.kicad_sch]
2026-03-24 add hc-sr04 test project with esp32 web dashboard
    [HcSr04Test.kicad_pcb, HcSr04Test.kicad_sch]
2026-03-24 feat: add 24V RGB LED strip test sketch
2026-04-07 add PlatformIO ESP32 project with HC-SR04, NFC, and analytics dashboard
    - 4-slot HC-SR04 ultrasonic sensors for product detection with configurable thresholds
    - PN532 NFC reader over I2C with 2.5s debounce
    - LittleFS-backed analytics DB: hourly records (7 days) + transaction log (200 entries)
    - Web dashboard (AP mode) with live, analytics, and transactions tabs
    - Filtering by time range, slot, and UID search
2026-04-07 add OpenSCAD mounts for HC-SR04 sensors and NFC module V3
    - Dual vertical HC-SR04 mount (65mm spacing), print twice for 4 slots
    - Quad HC-SR04 mount (side-by-side alternative)
    - PN532 NFC Module V3 enclosure with faceplate and antenna window
    [hc_sr04_dual_mount.scad, hc_sr04_quad_mount.scad, nfc_module_v3_mount.scad]
2026-05-19 Replace placeholder VendingMachine projects with real implementation
    AutomationStudio/VendingMachine/: Full B&R AS project for X20CP1382
    - Visualization (10 pages: Main, Zahlungsart, Bar/Karte, Ausgabe, Danke, Fehler, Settings)
    - State machine for payment flow (idle -> method choice -> cash/card -> motor -> done)
    - 4 Fach data structures (preisCent, istLeer, abstandCm, referenzCm, name)
    - Coin counter program (light barrier debouncing)
    - 5 digital inputs from ESP32: diEspFach[0..3] (HIGH=VOLL/LOW=LEER) + diEspNfc
    - Motors driven directly via doMotor[] with Perm_motorLaufzeit[] timing
    Arduino/VendingMachine/: ESP32 firmware (Snackomat)
    - HC-SR04 ultrasonic distance sensors (rou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
    [Cyclic.cpp, Init.cpp, VendingMachine.ino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]
2026-06-02 fix: Active-LOW Relay-Invertierung fuer Elegoo 8-Kanal-Relaismodul
    doMotor[]=0 aktiviert Relais (LOW=EIN), doMotor[]=1 deaktiviert (HIGH=AUS).
    Init.cpp setzt alle Motoren auf 1 beim Hochfahren - verhindert ungewollten Motorstart.
    [Cyclic.cpp, Init.cpp]
2026-06-09 Restructure VendingMachine as PlatformIO project; ESP32 = sensor/NFC node
    - Move sources into src/, add platformio.ini (esp32dev, Adafruit PN532)
    - Remove motor control: ESP32 only reports Fach-Status + NFC to the SPS
    over 5 digital lines via the Elegoo relay as 3.3V->24V level-shifter
    - Keep direct logic (HIGH=VOLL); active-LOW relay matches existing PLC
    inversion, so no firmware-side re-inversion
    - Add CLAUDE.md with architecture, pin map, wiring and flash notes
    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
